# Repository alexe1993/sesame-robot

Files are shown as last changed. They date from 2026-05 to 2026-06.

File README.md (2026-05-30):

# The Sesame Robot Project 
___







sesame-cover

<p align="center">
  <a href="https://www.youtube.com/watch?v=NIgoQVQF_Ng">
    tutorial-button
  </a>
  <a href="https://discord.gg/XDXkhQd8bC">
    discord-button
  </a>
</p>

___

**Greetings, from your new best friend.**

Sesame is an accessible Open-Source robotics project based on the ESP32 microcontroller system, with an emphasis on expression and movement. 
This project is designed for makers and engineers of all skill levels! Sesame offers a dynamic platform designed to start working with walking robots. 
To build a sesame robot, you will need basic soldering skills, $50-60 in hardware components, access to a 3D printer, and a basic understanding of Arduino IDE.

This repository contains the CAD design files, STL files, build and wiring guides, and the base/expanded firmware for the ESP32-based controller. 
There is also some included debugging firmware that may be helpful in getting your Sesame up and running.

## Features

*   **Quadruped Design:** Uses 8 servo motors (2 per leg) to achieve roughly 8 total degrees of freedom.
*   **Emotive Display:** Features a 128x64 OLED screen acting as a reactive face that syncs with movement.
*   **Fully Printable:** Designed entirely for 3D printing in PLA with minimal supports.
*   **Network Connectivity:** Connect to your WiFi network for remote control and API access.
*   **JSON API:** RESTful API for programmatic control from Python, JavaScript, and more.
*   **Conversational Faces:** Expressive emotion library with talk variants for voice assistant projects.
*   **Sesame Studio:** New animation composer software to easily create custom movements.
*   **Sesame Companion App:** Python application for voice control and advanced interactions.
*   **Serial CLI:** Control the robot and trigger animations via a Serial Command Line Interface or the web UI.
*   **Pre-programmed Emotes:** Includes animations for Walking, Waving, Dancing, Pointing, Resting, and more.

## Watch the launch video on YouTube

<a href="https://www.youtube.com/watch?v=1UDsWkcQZhc">thumb-youtube</a>

___

## Getting Started

Follow these steps to build your own Sesame Robot:

### 1. Gather Parts 
Check the **[Bill of Materials (BOM)](hardware/bom/README.md)** for a complete list of required electronics and hardware.
*   Microcontroller: Lolin S2 Mini (recommended for DIY builds), Sesame Distro Board V3 (Current, pre-flashed, supports Bambu Lab battery), V2 (legacy, USB-only), or ESP32-DevKitC-32E with Distro Board V1 (legacy)
*   Actuators: 8x MG90 Servos
*   Power: 5V 3A source (USB-C PD for S2 Mini and V2 Distro Board, or battery + buck converter; see BOM for the Bambu Lab 14500 7.4V 800mAh Li-ion Battery option)

### 2. Print Parts 
Download the STLs and follow the **[Printing Guide](hardware/printing/README.md)**.
*   Designed for PLA
*   Minimal supports required

### 3. Build & Wire 
Follow the **[Build Guide](docs/build-guide/README.md)** and **[Wiring Guide](docs/wiring-guide/README.md)** to assemble the frame and connect the electronics.

### 4. Flash Firmware 
Upload the code from the **[Firmware Directory](firmware/README.md)**.
*   Requires Arduino IDE
*   Configure WiFi AP settings

### 5. Create Animations 
Use **[Sesame Studio](software/sesame-studio/README.md)** to visually design poses and sequences for your robot.

sesame-wakeup-gif

---

## Software & Firmware

### Sesame Studio
Sesame Studio is a standalone desktop application included in `software/sesame-studio/`. It allows you to:
*   Visually pose the robot using a schematic interface.
*   Generate C++ code for servo angles automatically.
*   Sequence frames into complex animations.

[**> Go to Sesame Studio**](software/sesame-studio/README.md)

### Sesame Simulator
The Sesame Simulator, created by Jay Li, is a Rust-based 3D simulation environment for testing Sesame's movements and kinematics in a virtual space. It features:
*   **Physics-based Simulation:** Test walking and balance without hardware.
*   **Web-based Interface:** Run the simulator directly in your browser.
*   **URDF Integration:** Accurate modeling of Sesame's physical properties.

[**> Go to Sesame Simulator**](https://one-for-all.github.io/sesame-robot-sim/)

### Sesame Companion App
The Sesame Companion App is a Python-based application that enables advanced control and interaction with your robot over your local network. It leverages the new JSON API and network mode features to provide:
*   **Voice Assistant Integration:** Control Sesame with voice commands and see real-time emotional expressions.
*   **Remote Control:** Command your robot from anywhere on your local network.
*   **Face Control:** Change expressions dynamically based on conversation or context.
*   **API Examples:** Reference implementation for building your own integrations.

The Companion App works with robots running the latest firmware with network mode enabled.

[**> Go to Sesame Companion App Repository**](https://github.com/dorianborian/sesame-companion-app)

### Firmware
The ESP32 firmware (`sesame-firmware-main.ino`) handles the kinematics, face display, and WiFi control interface.
*   **Web UI:** Control the robot from your phone via the built-in Access Point.
*   **Custom Faces:** Add your own bitmaps (guide in firmware docs).

[**> Go to Firmware Docs**](firmware/README.md)

---

## Contributing

This robot is a platform for building new features, cosmetics, tools, and ideas. Since the current firmware is a basic implementation, pull requests are very welcome for:
*   Kinematics improvements
*   New animations
*   Improved Web UI/UX
*   Sensor integration (Ultrasonic, Gyro, etc.)

I would also love to see forks of this project with new hardware, software, faces, etc. Be sure to send me a message if you end up building one, and I might feature you on my website or channel!
  
---

*Created by [Dorian Todd](https://www.doriantodd.com/). Need help with your Sesame Robot? Send me a message on Discord, my username is "starphee"*

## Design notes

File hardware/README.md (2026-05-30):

# Hardware

All mechanical and electrical source files for the Sesame Robot live here. The hardware stack supports multiple build paths:

- **Hand-wired / Lolin S2 Mini build** for simple protoboard construction (recommended for DIY builds).
- **Custom Sesame Distro Board V3 build** (Current) for a professional SMD design with USB-C PD 12V and specific connector for Bambu Lab battery (included in new Sesame Build Kits, pre-flashed).
- **Custom Sesame Distro Board V3/V2 build** (Legacy) professional SMD design but plagued with brownouts on battery. Recommended for USB only or bypassing the buck converter.
- **Custom Sesame Distro Board V1 build** (legacy) for ESP32-DevKitC-32E stackup (phased out but still supported).

Use the sections below to jump to the files that match the version you are assembling.

## Directory Guide

| Folder | What you will find |
| --- | --- |
| [bom](bom/README.md) | Full bill of materials covering both wiring approaches, plus power budget notes and links back to the build tutorial. Start here to gather every component before printing or soldering. |
| [cad](cad/README.md) | Parametric STEP and Fusion 360 source models for every printed part. Great for remixing joint geometry or adapting the shell—just note the caution about features that may not translate across CAD packages. |
| [pcb](pcb/README.md) | Sesame Distro Board V3 (current), V2 (legacy), and V1 (legacy) schematics, layout files, Gerber files, BOM, and Pick-and-Place files. Includes ordering instructions for PCBway fabrication and assembly services. |
| [printing](printing/README.md) | Practical PLA print settings, support callouts, and image references for joint orientation and the top cover’s manual supports. |

## Getting Started

1. **Decide on a wiring strategy.** Review the comparison section in [docs/wiring-guide/README.md](../docs/wiring-guide/README.md) to choose between the protoboard and custom PCB routes. The Lolin S2 Mini build is recommended for DIY builders. If you have a Sesame Build Kit, your V3 (or early V2) Distro Board is already pre-flashed and ready to use.
2. **Print the shell and joints.** Follow the presets in [printing/README.md](printing/README.md) to prep the 3D files from `hardware/printing/stl`.
3. **Source electronics.** Use the line-by-line list in [bom/README.md](bom/README.md) and verify your power supply meets the 5V/3A requirement.
4. **Assemble electronics.** Reference either the hand-wiring steps or the appropriate Distro Board guide plus the wiring diagrams in `docs/wiring-guide/`.

> [!TIP]
> Keep photos of your wiring progress. They are invaluable for troubleshooting later and help when sharing build notes with the community.

## Supporting Documents

- [docs/build-guide/README.md](../docs/build-guide/README.md) for end-to-end assembly sequencing.
- [docs/wiring-guide/README.md](../docs/wiring-guide/README.md) for wiring diagrams, safety notes, and packing tips.

Improvements, remixes, and test reports are welcome, file issues or PRs with any updates you discover while building. <3

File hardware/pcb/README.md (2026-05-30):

# PCB Schematics

Electronic schematics and PCB designs for the Sesame Robot Project. There are two versions of the Sesame Distro Board available: V3 (current), V2 (legacy), and V1 (legacy).

> [!NOTE]
> **For Sesame Build Kits:** All Sesame Build Kits include a pre-flashed Sesame Distro Board V3 (or earlier V2), so you don't need to order or assemble a board separately.

> [!TIP]
> **Building from Scratch?** If you're building a Sesame Robot from scratch, we recommend using the **S2 Mini with hand wiring approach** for the easiest assembly experience. The V2/V3 distro boards use advanced SMD components that require specialized soldering skills or PCB assembly services.

---

## Sesame Distro Board V3 (Current)

The **Sesame Distro Board V3** is the latest version and features:

- **ESP32-S3 Processor**
- **USB-C PD 12V** (requires high quality PD charger cable)
- **Bambu Lab 14500 Battery Connector** for cheap and effective battery powering (priority feature)
- One-click order link via PCBway: [Order On PCBway!](https://www.pcbway.com/project/shareproject/Sesame_Distro_Board_V3_377de6fe.html)
- Limited stock of pre-assembled units: [Full Contact Engineering](https://fullcontactengineering.com/products/sesame-distro-board-v3-pcb)
  *Note: Due to time constraints, the USB-C PD 12V negotiation chip is slightly untested, so a high quality PD cable is necessary.*

### V3 Board Details and Schematics:

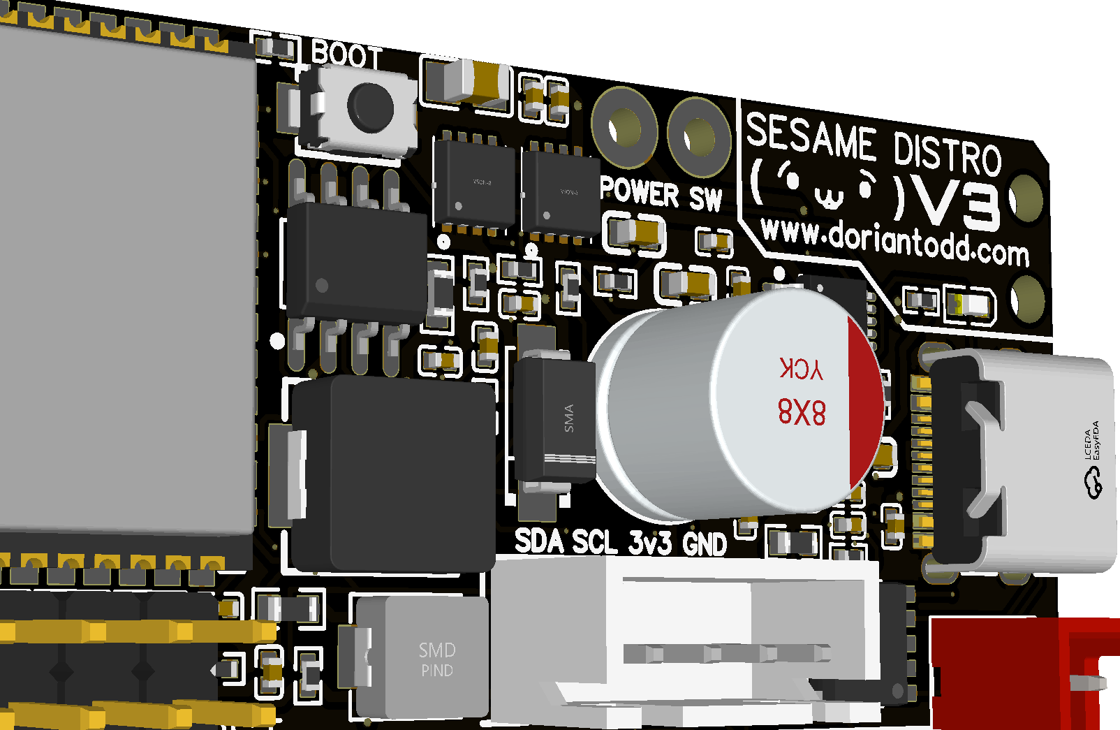
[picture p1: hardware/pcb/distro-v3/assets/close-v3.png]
Sesame Distro Board V3 Close-up


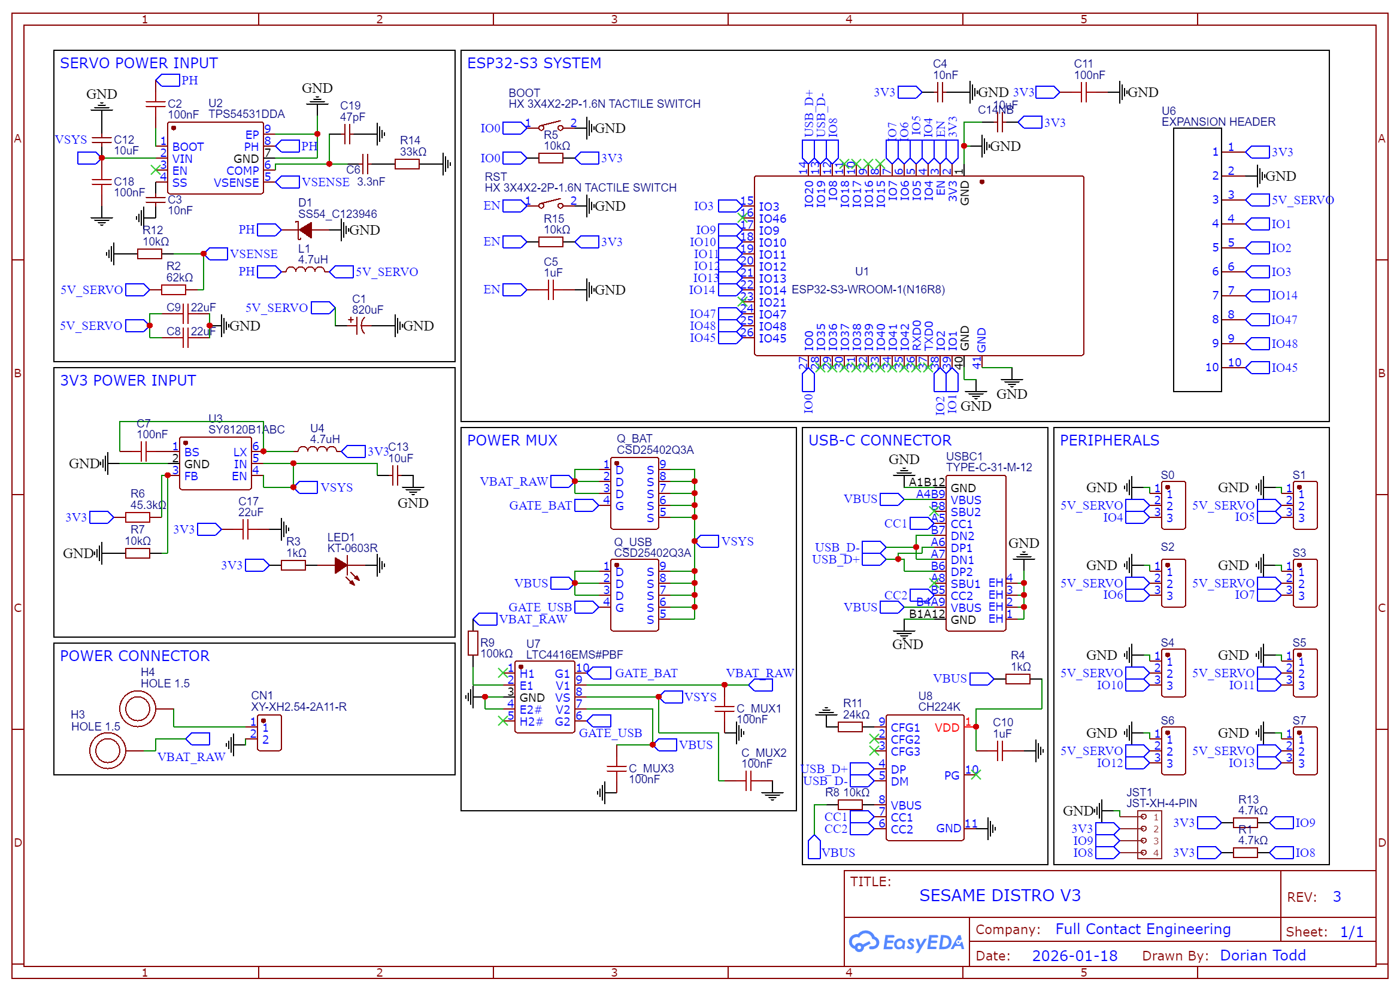
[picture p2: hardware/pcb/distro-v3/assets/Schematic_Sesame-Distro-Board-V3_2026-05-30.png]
Schematic_Sesame-Distro-Board-V3


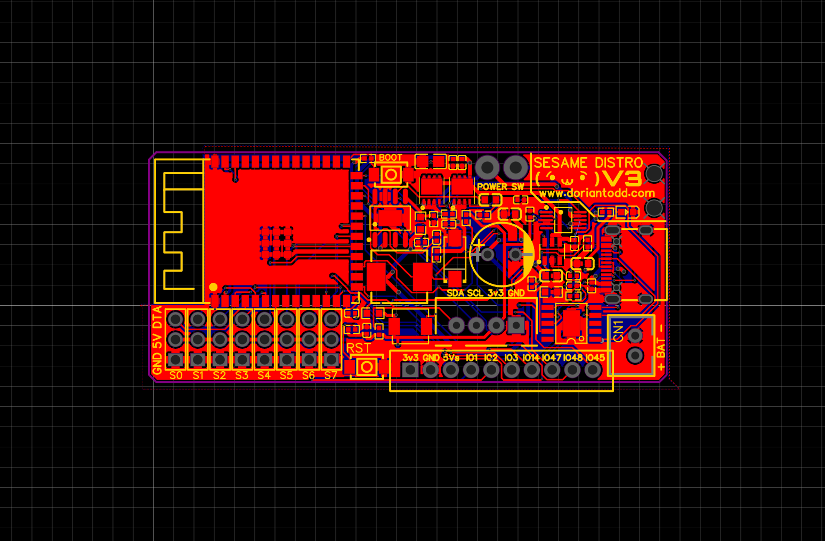
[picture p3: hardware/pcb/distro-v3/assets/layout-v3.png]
Sesame Distro Board V3 Layout


### V3 Files Available

All files are located in the [`distro-v3/`](distro-v3/) directory:

- **Schematic source:** `SCH_Sesame-Distro-Board-V3.json` - EasyEDA source design file for the V3 schematic
- **Gerber file:** `Gerber_Sesame-Distro-Board-V3_PCB.zip` - For PCB fabrication
- **BOM file:** `BOM_Sesame-Distro-Board-V3.csv` - Bill of materials for SMD components
- **Pick-and-Place file:** `PickAndPlace_PCB_Sesame-Distro-Board-V3.csv` - Component placement data for assembly

## Sesame Distro Board V2 (Legacy)

The **Sesame Distro Board V2** is an older version. *Major instabilities on battery power (brownouts due to buck converter handling) restrict this to USB only, or you must bypass the chip by soldering a separate buck converter directly to the power line. I may have extra V3 boards to send to those who ordered V2.*

### V2 Assembly Options (Legacy)

The V2 board consists entirely of SMD (surface-mount) components, which are **advanced to hand solder**. We recommend:

1. **PCB Assembly Service (Recommended):** Use [PCBway&#39;s PCB assembly service](https://www.pcbway.com/pcb-assembly.html) to have the board professionally assembled. Upload the Gerber, BOM, and Pick-and-Place files to their assembly service.
2. **Hand Soldering (Advanced Only):** Only attempt hand soldering if you're experienced with SMD components and have the proper tools (hot air station, fine-tip soldering iron, flux, etc.).

### V2 Files Available

All files are located in the [`distro-v2/`](distro-v2/) directory:

- **Schematic source:** `SCH_Sesame-Distro-Board-V2_2026-03-06.json` - EasyEDA source design file for the V2 schematic
- **Gerber file:** `Gerber_Sesame-Distro-V2_PCB.zip` - For PCB fabrication
- **BOM file:** `BOM_Sesame-Distro-V2.csv` - Bill of materials for SMD components
- **Pick-and-Place file:** `PickAndPlace_PCB_Sesame-Distro-V2.csv` - Component placement data for assembly

### PCBway / JLCPCB Sourcing Notes

When uploading the BOM to PCBway or JLCPCB for assembly, note the following three components that require special handling:

| Designator | Issue | Corrected Part | LCSC # |
| --- | --- | --- | --- |
| `U5`, `U7` | **Solder Pads** — these are copper pads only, no physical component is needed. Remove these lines from the BOM when ordering assembly. | N/A | N/A |
| `5-12V` | 2-pin 3.5 mm screw terminal. Original part `1984617` (Phoenix Contact) cannot be sourced. | `XY302V-3.5-2P` | [C784940](https://www.lcsc.com/product-detail/C784940.html) |
| `JST-XH` | 4-pin JST XH connector. Original `JST-XH-4-PIN` cannot be sourced. | `B4B-XH-A(LF)(SN)` | [C144395](https://www.lcsc.com/product-detail/C144395.html) |

The BOM CSV has already been updated with the corrected parts. The solder-pad rows are marked **"No Part Required"** in the Name field so they are easy to identify and exclude.

---

## Sesame Distro Board V1 (Legacy)

> [!CAUTION]
> The Sesame Distro Board V1 is now **phased out** but still supported. V1 has some limitations: it won't run on tethered power (e.g., USB-C) and is harder to assemble than other options. V1 is still supported with wiring guides and firmware and works on battery power. If you have a V1 board, you can still use it successfully.

The Distro Board V1 pairs with the ESP32-DevKitC-32E.

> [!IMPORTANT]
> **ESP32 Pin Header Requirement:** The distro board V1 stacks on top of the ESP32-DevKitC-32E, so you need an ESP32 board **without pre-soldered pin headers**. If your board came with headers already soldered on the top, you will need to desolder all of the headers and flip them to the bottom side of the ESP32 board so the distro board can mount on top.

### V1 Board Schematic:

Schematic_Sesame-Distro-Board

### V1 Files Available

All files are located in the [`distro-v1/`](distro-v1/) directory.

---

## PCBway Sponsorship

**PCBway Sponsorship**

This project was sponsored by [PCBway](https://www.pcbway.com/), who manufactured the custom distro boards. PCBway offers high-quality PCB fabrication services with fast turnaround times and excellent customer support.

If you're building your own Sesame Robot, PCBway is a great option for getting professional-quality PCB fabrication and assembly services at reasonable prices:

- **PCB Fabrication:** Upload Gerber files to get boards manufactured
- **PCB Assembly:** Upload Gerber, BOM, and Pick-and-Place files for fully assembled boards (recommended for V2)

pcbs-from-pcbway

---

## How to Order

### Ordering V3 Boards (Current)

**Option 1: Pre-assembled Units (Recommended)**
Depending on stock availability, you can buy fully populated, pre-flashed boards directly from [Full Contact Engineering](https://fullcontactengineering.com/products/sesame-distro-board-v3-pcb).

**Option 2: PCBway Assembly Service**

1. Go to [PCBway&#39;s Shared Project Page](https://www.pcbway.com/project/shareproject/Sesame_Distro_Board_V3_377de6fe.html)
2. Add to cart to order the boards fully assembled!

**Option 3: Manual PCBway Assembly Service Upload**

1. Go to [PCBway&#39;s PCB Assembly service](https://www.pcbway.com/pcb-assembly.html)
2. Upload the Gerber file: `distro-v3/Gerber_Sesame-Distro-Board-V3_PCB.zip`
3. Upload the BOM file: `distro-v3/BOM_Sesame-Distro-Board-V3.csv`
4. Upload the Pick-and-Place file: `distro-v3/PickAndPlace_PCB_Sesame-Distro-Board-V3.csv`
5. Confirm board specifications and component availability

### Ordering V2 Boards (Deprecated)

**Option 1: PCB Assembly Service (Recommended)**

1. Go to [PCBway&#39;s PCB Assembly service](https://www.pcbway.com/pcb-assembly.html)
2. Upload the Gerber file: `distro-v2/Gerber_Sesame-Distro-V2_PCB.zip`
3. Upload the BOM file: `distro-v2/BOM_Sesame-Distro-V2.csv`
4. Upload the Pick-and-Place file: `distro-v2/PickAndPlace_PCB_Sesame-Distro-V2.csv`
5. Confirm board specifications and component availability
6. Place your order to receive fully assembled boards

**Option 2: Fabrication Only (For Advanced Users)**

1. Download the Gerber file from [`distro-v2/Gerber_Sesame-Distro-V2_PCB.zip`](distro-v2/Gerber_Sesame-Distro-V2_PCB.zip)
2. Upload to [PCBway](https://www.pcbway.com/) or another PCB manufacturer
3. Confirm board specifications in the preview
4. Order the bare PCBs and hand-solder SMD components yourself (advanced)

### Ordering V1 Boards (Legacy)

1. Download the Gerber file from [`distro-v1/Gerber_Sesame-Distro-Board_PCB_Sesame-Distro-Board_V1.zip`](distro-v1/Gerber_Sesame-Distro-Board_PCB_Sesame-Distro-Board_V1.zip)
2. Upload to [PCBway](https://www.pcbway.com/) or another PCB manufacturer
3. Confirm board specifications in the preview
4. Place your order to receive bare V1 boards

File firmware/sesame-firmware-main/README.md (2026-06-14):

# esame Robot Firmware

This document provides technical information on the firmware architecture, control logic, and hardware abstraction layers used in the Sesame Robot.

> [!NOTE]
> The firmware is now organized into a modular structure with a main entry point and specialized header files for bitmaps, movement, and web assets. This makes customization much easier and the codebase cleaner.

## Table of Contents

- [How to Flash the Firmware](#how-to-flash-the-firmware)
- [Network Configuration](#network-configuration--connectivity)
- [API Reference](#api-reference)
  - [Legacy Web Endpoints](#legacy-web-endpoints)
  - [JSON API](#json-api-recommended-for-network-clients)
  - [Python Examples](#python-api-example)
  - [JavaScript Examples](#nodejsjavascript-example)
- [Advanced Integration Examples](#advanced-integration-examples)
  - [Voice Assistant Integration](#voice-assistant-integration)
  - [Home Automation](#home-automation-integration)
- [Idle Animation System](#idle-animation-system)
- [Firmware Architecture](#firmware-architecture)
- [Technical Implementation](#technical-implementation-overview)
- [Asset Pipeline &amp; Face Customization](#asset-pipeline--face-customization)
- [Hardware Abstraction Layer](#hardware-abstraction-layer-hal)

## How to Flash the Firmware

> [!NOTE]
> **Sesame Build Kit Users:** Your Distro Board V3 (and earlier V2) kits come pre-flashed with the latest firmware. You only need to flash firmware if you want to customize it or update to a newer version.

### Prerequisites

1. **Arduino IDE** (version 2.0 or higher recommended)
2. **ESP32 Board Support**: Install via Arduino IDE's Board Manager
   - Open Arduino IDE
   - Go to **File → Preferences**
   - Add to "Additional Board Manager URLs": `https://raw.githubusercontent.com/espressif/arduino-esp32/gh-pages/package_esp32_index.json`
   - Go to **Tools → Board → Boards Manager**
   - Search for "ESP32" and install "ESP32 by Espressif Systems" (v2.0.0 or higher)
3. **Required Libraries** (install via Library Manager):

- `Adafruit PWM Servo Driver Library`
- `Adafruit SSD1306`
- `Adafruit GFX Library`

> [!IMPORTANT]
> The firmware expects a PCA9685 servo driver at I2C address `0x40`. The SSD1306 display shares the same SDA/SCL bus and is detected at `0x3C` or `0x3D`.

### Flashing Steps

1. **Connect your board** via USB to your computer
2. **Open the firmware**:

   - Open [sesame-firmware-main.ino](sesame-firmware-main.ino) in Arduino IDE
   - Make sure you have it in a folder with the same name.
   - Also include all of the .h header files.
3. **Select your board**:

   - Go to **Tools → Board**
   - For Lolin S2 Mini: Select "LOLIN S2 Mini"
   - For Sesame Distro Board V1: Select "ESP32 Dev Module"
   - For Sesame Distro Board V2 or V3: Select "ESP32S3 Dev Module"
4. **Configure board settings**:

   - **For Lolin S2 Mini**:
     - **Upload Speed**: 921600
     - **USB CDC On Boot**: "Enabled"
     - **Partition Scheme**: "Default 4MB with spiffs"
   - **For Distro Board V2 or V3 (ESP32-S3)**:
     - **USB CDC On Boot**: "Enabled" (Required for Serial Monitor)
     - **Flash Mode**: "QIO 80MHz"
     - **Partition Scheme**: "Default 4MB with spiffs"
5. **Select the correct port**:

   - Go to **Tools → Port** and select your ESP32's COM port
6. **Choose your board configuration** in the code:

   - Open [sesame-firmware-main.ino](sesame-firmware-main.ino)
   - The firmware uses `Wire.begin()` and the selected board's default I2C pins.
   - Connect servos 0-7 to PCA9685 channels 0-7. No individual ESP32 servo GPIO configuration is required.
7. **(Optional) Configure network mode**:

   - If you want the robot to connect to your WiFi network (for API access and remote control), edit the network configuration section (around line 17-22):

   ```cpp
   #define NETWORK_SSID "YourNetworkName"  // Your WiFi network name
   #define NETWORK_PASS "YourPassword"     // Your WiFi password
   #define ENABLE_NETWORK_MODE true        // Set to true to enable
   ```

   - Leave `ENABLE_NETWORK_MODE false` to use Access Point mode only
8. **Upload the firmware**:

   - Click the **Upload** button (→) in Arduino IDE
   - Wait for compilation and upload to complete
9. **Test the connection**:

   - Open Serial Monitor (**Tools → Serial Monitor**, set baud rate to 115200)
   - Reset the board - you should see startup messages and network information
   - The serial monitor provides individual motor control for testing and troubleshooting
   - **If using AP mode only**: Connect to the "Sesame-Controller-BETA" WiFi network (password: `12345678`) and navigate to any website
   - **If using network mode**: Look for the "Connected to network!" message in Serial Monitor, then access via `http://sesame-robot.local` or the displayed IP address

### Troubleshooting

- **Linux USB Permissions**: If your port isn't showing up or you get "Permission Denied", you likely need to add your user to the `dialout` group: `sudo usermod -a -G dialout $USER`. Log out and back in for changes to take effect.
- **Upload fails**: Try holding the BOOT button while uploading, or try a different USB cable. For S3-based boards, the "USB CDC On Boot" setting is critical for finding the port after a reset.
- **Port not found**: Install the appropriate USB drivers (CP210x for S2 Mini, CH340 for some ESP32 boards). Windows 10/11 usually includes these.
- **Robot not moving**: Check power supply and servo connections; increase `motorCurrentDelay` in web settings if brownouts occur
- **Can't connect to network**:
  - Verify `ENABLE_NETWORK_MODE` is set to `true` and SSID/password are correct
  - Check Serial Monitor for connection status - look for "Connected to network!" or error messages
  - Ensure your WiFi network is 2.4GHz (ESP32 does not support 5GHz)
  - Try increasing the connection timeout in the code (currently 10 seconds / 20 attempts)
- **mDNS hostname not resolving**:
  - On Windows, install [Bonjour Print Services](https://support.apple.com/kb/DL999)
  - On Linux, ensure `avahi-daemon` is installed and running
  - Try accessing via IP address instead (check Serial Monitor for the assigned IP)
  - Some routers block mDNS traffic - check router settings or use IP address
- **API commands not working**:
  - Ensure you're sending POST requests to `/api/command` (not GET)
  - Verify `Content-Type: application/json` header is set
  - Check Serial Monitor for error messages and parsed command output
  - Test with a simple cURL command first to verify connectivity

## Firmware Architecture

The firmware is split into several key files to keep the logic organized and assets easy to manage:

- **[sesame-firmware-main.ino](sesame-firmware-main.ino)**: The main entry point containing the `setup()`, `loop()`, core system logic, network configuration, and API endpoints.
- **[face-bitmaps.h](face-bitmaps.h)**: A dedicated header for OLED face macros and raw bitmap data. Now includes extensive conversational faces for voice assistant integration.
- **[movement-sequences.h](movement-sequences.h)**: Definitions for all procedural movement and pose animations.
- **[captive-portal.h](captive-portal.h)**: Contains the HTML, CSS, and JS for the web-based remote control interface.

## Technical Implementation Overview

The firmware is built on the Arduino-ESP32 framework. It runs on a single-core event loop and delegates servo PWM generation to a PCA9685 driver.

### PWM & Servo Kinematics

- **External PWM**: A PCA9685 at I2C address `0x40` generates all eight 50 Hz servo signals, avoiding ESP32 PWM timer allocation and direct servo GPIO wiring.
- **Pulse Width Mapping**: Leg servos are mapped from degrees (0-180) to microseconds (500us to 2500us), matching the tested PCA9685 Spider sketch. Edit `SERVO_MIN_US` and `SERVO_MAX_US` near the top of `sesame-firmware-main.ino` for a different servo range.
- **Staggered Activation**: To prevent VCC rail collapse (brownout) caused by simultaneous inductive loads, the `setServoAngle` helper introduces a mandatory `motorCurrentDelay` (default 20ms) between sequential pulses. This delay should be tweaked to your power setup. If you have a strong dedicated power supply you can try setting it to zero. It can also be changed while running through the AP controller settings menu.

### Communication & Networking Stack

- **Dual-Mode WiFi**: The ESP32 can simultaneously operate in both Access Point mode (for direct connections) and Station mode (connected to an existing network) using `WiFi.mode(WIFI_AP_STA)`.
- **SoftAP & Captive Portal**: The ESP32 initializes an Access Point using `WiFi.softAP()`. A `DNSServer` listens on UDP Port 53, using a wildcard "*" redirect to map all DNS queries to the internal gateway (`192.168.4.1`).
- **mDNS Service Discovery**: The firmware broadcasts `sesame-robot.local` via Multicast DNS (mDNS) using the `ESPmDNS` library, allowing network discovery without hardcoded IP addresses.
- **RESTful API Surface**: The `WebServer` handles both legacy URL-parameter endpoints and modern JSON-based API:
  - `/cmd?go=[dir]`: Legacy movement control
  - `/cmd?pose=[name]`: Legacy pose triggers
  - `/api/status`: JSON status endpoint (GET)
  - `/api/command`: JSON command endpoint (POST) - supports face-only updates and combined face+movement commands
  - `/getSettings` / `/setSettings`: Parameter configuration
- **Face-Only Command Support**: The `/api/command` endpoint intelligently detects face-only requests (no `command` field) and updates the display without triggering movement animations.
- **Non-Blocking Control Flow**: Instead of `delay()`, the firmware uses a custom `pressingCheck(String cmd, int ms)` function. This function polls `server.handleClient()` and `dnsServer.processNextRequest()` during animation frames, allowing for real-time interruptibility (e.g., immediate stop on button release). This pressingCheck protocol can be used for motion commands like walking to play each motion only when the button is held.

### Display & Graphics Subsystem

- **Shared I2C Bus**: The PCA9685 (`0x40`) and SSD1306 (`0x3C` or `0x3D`) share the ESP32 hardware I2C bus.
- **Memory Management (`PROGMEM`)**: Large 128x64 bitmap arrays (1024 bytes per frame) are stored in Flash memory using the `PROGMEM` attribute.
- **Macro-Based Asset Management**: The firmware uses a `FACE_LIST` macro in [face-bitmaps.h](face-bitmaps.h) to automatically register and handle new faces, reducing the boilerplate required when adding animations.
- **Rendering Pipeline**: The `updateAnimatedFace()` function manages frame rates and sequence looping outside of the main movement logic to ensure smooth visual feedback even during complex movements.
- **Dynamic WiFi Info Overlay**: The `updateWifiInfoScroll()` function composites scrolling connection information over the face bitmap during the first 30 seconds of operation (before first input), drawing the face as background with a black bar and white text overlay for readability.
- **Idle Animation System**: Implements realistic idle behavior with randomized blinking (including double-blinks) and boomerang face animations, triggered automatically when no input is detected.

## Prerequisites & Development Environment

- **Board Support**: ESP32 by Espressif Systems (v2.0.0+ recommended). Lolin S2 Mini and ESP32-WROOM32 DevKitC are best supported.
- **Libraries**:
  - `Adafruit_PWMServoDriver`: PCA9685 servo PWM control.
  - `Adafruit_SSD1306` & `Adafruit_GFX`: Buffer-based OLED rendering.
  - `ESPmDNS`: mDNS service discovery (included with ESP32 board support).
  - `DNSServer`: Captive portal DNS redirection (included with ESP32 board support).
  - `WebServer`: HTTP server implementation (included with ESP32 board support).
- **Tooling**: Arduino IDE 2.0+ recommended.

## Network Configuration & Connectivity

The firmware now supports **dual-mode WiFi operation**, allowing the robot to simultaneously act as an Access Point (for direct connections) and connect to your existing WiFi network (for integration with other devices and remote control).

### Access Point Mode (Default)

By default, the robot creates its own WiFi network:

- **SSID**: `Sesame-Controller-BETA`
- **Password**: `12345678` (Some devices may require you to change this if the default isn't connecting)
- **IP Address**: `192.168.4.1`

Connect to this network and navigate to any website to access the captive portal control interface. If you're having trouble connecting, try changing the password to something custom in the code's `#define AP_PASS` section.

### Network Mode (Optional)

To connect the robot to your home or office WiFi network:

1. **Enable Network Mode** in [sesame-firmware-main.ino](sesame-firmware-main.ino):

   ```cpp
   #define NETWORK_SSID "YourNetworkName"  // Your WiFi network name
   #define NETWORK_PASS "YourPassword"     // Your WiFi password
   #define ENABLE_NETWORK_MODE true        // Set to true to enable
   ```
2. **Flash the updated firmware** to your robot.
3. **Access via multiple methods**:

   - **mDNS Hostname**: `http://sesame-robot.local` (works on most devices)
   - **Network IP**: Check Serial Monitor at 115200 baud for the assigned IP address
   - **Still accessible via AP**: The robot maintains its Access Point even when connected to your network

### mDNS Discovery

The firmware includes an mDNS responder that broadcasts the hostname `sesame-robot.local` on your local network. This allows you to access the robot without knowing its IP address:

```bash
# Access from browser
http://sesame-robot.local

# Ping test
ping sesame-robot.local
```

**Note**: mDNS works natively on:

- macOS and iOS devices
- Linux with Avahi installed
- Windows 10+ (may require Bonjour service)

### Security Considerations

The firmware is designed for local network use and does not include authentication by default. When enabling network mode:

- **Local Network Only**: The robot responds to requests from any device on your network. Do not expose it to the internet without proper security measures.
- **No HTTPS**: Communication is unencrypted HTTP. Avoid transmitting sensitive data through the robot's API.
- **Access Point Password**: The default AP password is `12345678`. For production use, change `AP_PASS` in the firmware to a stronger password.
- **Trusted Networks**: Only connect your robot to trusted WiFi networks.

For enhanced security:

1. Change the default AP password to a strong, unique password
2. Use network segmentation (IoT VLAN) to isolate the robot from critical devices
3. Implement firewall rules to restrict access to specific IP addresses
4. Consider adding authentication headers in a custom firmware fork for production deployments

### WiFi Information Display

The robot's OLED screen now features an intelligent WiFi info system:

- **First 30 seconds**: If no input is received, WiFi connection information scrolls across the top of the display
- **After first input**: WiFi info disappears to show only faces
- **Dual-mode info**: When connected to both AP and network, displays both connection details

The scrolling text includes:

- Access Point SSID and IP
- Network name and IP (if connected)
- mDNS hostname
- Captive portal instructions

## API Reference

The firmware exposes both legacy web endpoints and a modern JSON-based API for programmatic control.

### Legacy Web Endpoints

These endpoints use URL parameters and are primarily used by the web interface:

#### Movement Control

```http
GET /cmd?go=forward
GET /cmd?go=backward
GET /cmd?go=left
GET /cmd?go=right
GET /cmd?stop
```

#### Pose Control

```http
GET /cmd?pose=wave
GET /cmd?pose=dance
GET /cmd?pose=rest
GET /cmd?pose=stand
# ... (see movement-sequences.h for all available poses)
```

#### Individual Motor Control

```http
GET /cmd?motor=1&value=90
# motor: 1-8 (motor number)
# value: 0-180 (angle in degrees)
```

#### Settings Management

```http
GET /getSettings
# Returns: {"frameDelay":100,"walkCycles":10,"motorCurrentDelay":20,"faceFps":8}

GET /setSettings?frameDelay=120&walkCycles=15&motorCurrentDelay=25&faceFps=10
```

### JSON API (Recommended for Network Clients)

The JSON API is designed for programmatic control from external devices, Python scripts, and IoT integrations.

#### Get Robot Status

```http
GET /api/status
```

**Response:**

```json
{
  "currentCommand": "forward",
  "currentFace": "walk",
  "networkConnected": true,
  "apIP": "192.168.4.1",
  "networkIP": "192.168.1.100"
}
```

#### Send Commands

```http
POST /api/command
Content-Type: application/json

{
  "command": "forward",
  "face": "walk"
}
```

**Response:**

```json
{
  "status": "ok",
  "message": "Command executed"
}
```

#### Face-Only Updates

Send a face change without triggering movement:

```http
POST /api/command
Content-Type: application/json

{
  "face": "happy"
}
```

**Response:**

```json
{
  "status": "ok",
  "message": "Face updated"
}
```

#### Stop Command

```http
POST /api/command
Content-Type: application/json

{
  "command": "stop"
}
```

### Available Commands

**Movement Commands:**

- `forward`, `backward`, `left`, `right` - Continuous movement (loops until stopped)
- `stop` - Immediately stop current movement

**Pose Commands (one-shot animations):**

- `rest`, `stand`, `wave`, `dance`, `swim`, `point`
- `pushup`, `bow`, `cute`, `freaky`, `worm`, `shake`
- `shrug`, `dead`, `crab`

**Available Faces:**

- Movement faces: `walk`, `rest`, `stand`, `dance`, `wave`, etc.
- Conversational faces: `happy`, `sad`, `angry`, `surprised`, `sleepy`, `love`, `excited`, `confused`, `thinking`
- Talk variants: `talk_happy`, `talk_sad`, `talk_angry`, etc.
- Special: `idle`, `idle_blink`, `default`

### Python API Example

```python
import requests
import time

# Robot IP or hostname
robot_url = "http://sesame-robot.local"

# Get status
response = requests.get(f"{robot_url}/api/status")
status = response.json()
print(f"Current face: {status['currentFace']}")

# Make robot wave and show happy face
requests.post(f"{robot_url}/api/command", json={
    "command": "wave",
    "face": "happy"
})

time.sleep(3)

# Just change face without moving
requests.post(f"{robot_url}/api/command", json={
    "face": "excited"
})

# Stop movement
requests.post(f"{robot_url}/api/command", json={
    "command": "stop"
})
```

### cURL Examples

```bash
# Get robot status
curl http://sesame-robot.local/api/status

# Make robot dance
curl -X POST http://sesame-robot.local/api/command \
  -H "Content-Type: application/json" \
  -d '{"command":"dance","face":"dance"}'

# Change face only
curl -X POST http://sesame-robot.local/api/command \
  -H "Content-Type: application/json" \
  -d '{"face":"happy"}'

# Stop movement
curl -X POST http://sesame-robot.local/api/command \
  -H "Content-Type: application/json" \
  -d '{"command":"stop"}'
```

### Node.js/JavaScript Example

```javascript
const robotURL = 'http://sesame-robot.local';

// Get status
fetch(`${robotURL}/api/status`)
  .then(res => res.json())
  .then(data => console.log('Robot status:', data));

// Send command
fetch(`${robotURL}/api/command`, {
  method: 'POST',
  headers: {'Content-Type': 'application/json'},
  body: JSON.stringify({
    command: 'wave',
    face: 'happy'
  })
})
.then(res => res.json())
.then(data => console.log('Response:', data));

// Face-only update
fetch(`${robotURL}/api/command`, {
  method: 'POST',
  headers: {'Content-Type': 'application/json'},
  body: JSON.stringify({face: 'surprised'})
})
.then(res => res.json())
.then(data => console.log('Response:', data));
```

## Advanced Integration Examples

### Voice Assistant Integration

The combination of conversational faces, the JSON API, and network mode makes the Sesame Robot perfect for voice assistant projects. Here's an example using Python with speech recognition:

```python
import requests
import speech_recognition as sr
from textblob import TextBlob
import time

robot_url = "http://sesame-robot.local"

def analyze_sentiment(text):
    """Analyze sentiment and return appropriate face"""
    blob = TextBlob(text)
    polarity = blob.sentiment.polarity
  
    if polarity > 0.5:
        return "excited"
    elif polarity > 0.2:
        return "happy"
    elif polarity < -0.5:
        return "angry"
    elif polarity < -0.2:
        return "sad"
    else:
        return "thinking"

def set_robot_face(face, talking=False):
    """Update robot's face expression"""
    if talking:
        face = f"talk_{face}"
  
    requests.post(f"{robot_url}/api/command", json={"face": face})

# Initialize speech recognition
recognizer = sr.Recognizer()

while True:
    with sr.Microphone() as source:
        print("Listening...")
        set_robot_face("idle")
    
        try:
            audio = recognizer.listen(source, timeout=5)
            set_robot_face("thinking")
        
            text = recognizer.recognize_google(audio)
            print(f"You said: {text}")
        
            # Determine emotion and show talking face
            emotion = analyze_sentiment(text)
            set_robot_face(emotion, talking=True)
        
            # Process command...
            time.sleep(2)
        
            # Return to neutral
            set_robot_face(emotion, talking=False)
        
        except sr.WaitTimeoutError:
            set_robot_face("sleepy")
        except sr.UnknownValueError:
            set_robot_face("confused")
```

### Home Automation Integration

Integrate with Home Assistant or other home automation platforms:

```python
# Home Assistant automation example
import requests

def robot_notification(message_type):
    """Display robot emotion based on notification type"""
    robot_url = "http://sesame-robot.local"
  
    emotion_map = {
        "doorbell": "surprised",
        "alarm": "angry",
        "reminder": "thinking",
        "success": "happy",
        "error": "sad"
    }
  
    face = emotion_map.get(message_type, "default")
    requests.post(f"{robot_url}/api/command", json={"face": face})
  
    # Optional: add movement
    if message_type == "doorbell":
        requests.post(f"{robot_url}/api/command", json={
            "command": "wave",
            "face": "happy"
        })
```

### WebSocket Streaming (Advanced)

For real-time control with minimal latency, you can poll the status endpoint or implement a simple state machine:

```javascript
// React/Vue.js real-time robot control
class RobotController {
  constructor(robotURL) {
    this.url = robotURL;
    this.currentFace = 'default';
  }
  
  async updateEmotion(emotion, isSpeaking) {
    const face = isSpeaking ? `talk_${emotion}` : emotion;
  
    if (face !== this.currentFace) {
      await fetch(`${this.url}/api/command`, {
        method: 'POST',
        headers: {'Content-Type': 'application/json'},
        body: JSON.stringify({face})
      });
  
      this.currentFace = face;
    }
  }
  
  async getStatus() {
    const res = await fetch(`${this.url}/api/status`);
    return await res.json();
  }
  
  async performAction(action, emotion = null) {
    const payload = {command: action};
    if (emotion) payload.face = emotion;
  
    await fetch(`${this.url}/api/command`, {
      method: 'POST',
      headers: {'Content-Type': 'application/json'},
      body: JSON.stringify(payload)
    });
  }
}

// Usage
const robot = new RobotController('http://sesame-robot.local');

// Set emotion without moving
await robot.updateEmotion('happy', false);

// Set talking face
await robot.updateEmotion('excited', true);

// Perform action with face
await robot.performAction('dance', 'excited');

// Check status
const status = await robot.getStatus();
console.log(`Robot is ${status.currentFace} and doing ${status.currentCommand}`);
```

## Idle Animation System

The firmware includes an intelligent idle animation system that activates automatically:

### Behavior

- **Activation**: When the robot has received no commands for a period, it enters idle mode
- **Idle Face**: Displays a gentle "breathing" animation using the `idle` face in `FACE_ANIM_BOOMERANG` mode
- **Blinking**: Randomly triggers blink animations (3-7 second intervals)
- **Double Blinks**: 30% chance of a double blink for realistic behavior
- **Exit**: Any movement command or input immediately exits idle mode

### Technical Implementation

The idle system uses:

- `enterIdle()` - Activates idle face with boomerang animation
- `exitIdle()` - Returns to normal operation
- `updateIdleBlink()` - Manages random blink timing and double-blink logic
- `scheduleNextIdleBlink()` - Randomizes blink intervals for natural appearance

To customize idle behavior, modify the timing values in [sesame-firmware-main.ino](sesame-firmware-main.ino):

```cpp
scheduleNextIdleBlink(3000, 7000);  // Min and max ms between blinks
```

## Asset Pipeline & Face Customization

The firmware includes an intelligent idle animation system that activates automatically:

### Behavior

- **Activation**: When the robot has received no commands for a period, it enters idle mode
- **Idle Face**: Displays a gentle "breathing" animation using the `idle` face in `FACE_ANIM_BOOMERANG` mode
- **Blinking**: Randomly triggers blink animations (3-7 second intervals)
- **Double Blinks**: 30% chance of a double blink for realistic behavior
- **Exit**: Any movement command or input immediately exits idle mode

### Technical Implementation

The idle system uses:

- `enterIdle()` - Activates idle face with boomerang animation
- `exitIdle()` - Returns to normal operation
- `updateIdleBlink()` - Manages random blink timing and double-blink logic
- `scheduleNextIdleBlink()` - Randomizes blink intervals for natural appearance

To customize idle behavior, modify the timing values in [sesame-firmware-main.ino](sesame-firmware-main.ino):

```cpp
scheduleNextIdleBlink(3000, 7000);  // Min and max ms between blinks
```

## Hardware Abstraction Layer (HAL)

The firmware uses the selected ESP32 board's default I2C pins. Servo outputs come from PCA9685 channels 0-7, while the SSD1306 display is connected to the same SDA/SCL bus.

### PCA9685 Channel Map

| Servo | PCA9685 Channel | Leg |
| ----- | --- | --- |
| Motor 0 | 0 | R1 |
| Motor 1 | 1 | R2 |
| Motor 2 | 2 | L1 |
| Motor 3 | 3 | L2 |
| Motor 4 | 4 | R4 |
| Motor 5 | 5 | R3 |
| Motor 6 | 6 | L3 |
| Motor 7 | 7 | L4 |

### ESP32 I2C Pins

| Board | SDA | SCL |
| ----- | --- | --- |
| Lolin S2 Mini | 33 | 35 |
| Sesame Distro Board V1 | 21 | 22 |
| Sesame Distro Board V2 / V3 | 8 | 9 |

Connect both the PCA9685 and SSD1306 to these SDA/SCL pins. Grounds must be common between the ESP32, PCA9685 logic, display, and servo power supply. Power the servos through the PCA9685 `V+` rail from a suitable external supply, not from the ESP32 3.3 V pin.

### Porting to Other ESP32 Variants

The firmware calls `Wire.begin()` to use the default SDA/SCL pins supplied by the selected Arduino board definition. For custom wiring, replace it with `Wire.begin(SDA_PIN, SCL_PIN)`; both pins must support output because I2C data and clock are bidirectional.

## Asset Pipeline & Face Customization

To maintain a clean main source file and optimize performance, face bitmaps are decoupled from the primary logic. Faces are managed in [face-bitmaps.h](face-bitmaps.h) using a "Single Source of Truth" macro system.

### Face Library

The firmware includes an extensive library of faces organized into three categories:

#### Movement Faces

Synchronized with physical poses and animations:

- `walk`, `rest`, `stand`, `swim`, `dance`, `wave`, `point`
- `pushup`, `bow`, `cute`, `freaky`, `worm`, `shake`, `shrug`
- `dead`, `crab`, `idle`, `idle_blink`

#### Conversational Faces

Designed for expressive communication and voice assistant integration:

- **Base emotions**: `happy`, `sad`, `angry`, `surprised`, `sleepy`, `love`, `excited`, `confused`, `thinking`
- **Talk variants**: `talk_happy`, `talk_sad`, `talk_angry`, `talk_surprised`, `talk_sleepy`, `talk_love`, `talk_excited`, `talk_confused`, `talk_thinking`

The "talk_" variants feature open mouths for lip-sync and animated speech. These faces are perfect for:

- Voice assistant projects (Alexa, Google Assistant, custom TTS)
- Chatbot interfaces controlled via the JSON API
- Interactive storytelling and educational applications
- Remote-controlled performances

#### Special Faces

- `default` - The startup/fallback face
- `idle` - Gentle breathing animation for idle state
- `idle_blink` - Blink animation triggered randomly during idle

### Adding Custom Faces

### Workflow:

1. **Image Creation**: Find faces using Kaomoji or [Emojicombos](https://emojicombos.com/kaomoji). Create a `128x64` image in a tool like [jsPaint](https://jspaint.app/).
2. **Bitmap Conversion**: Use [image2cpp](https://javl.github.io/image2cpp/) with `Horizontal` scaling, `128x64` resolution, and `Arduino Code` output.
3. **Registration**:
   - Add your face name to the `FACE_LIST` macro in [face-bitmaps.h](face-bitmaps.h).
   - Paste the generated C array into [face-bitmaps.h](face-bitmaps.h) right after the last bitmap in the list.
   - (Optional) For animations, add numbered suffixes (e.g., `_1`, `_2`) and register the FPS in the `faceFpsEntries` in [sesame-firmware-main.ino](sesame-firmware-main.ino).

### Animating Faces

For an animation to be recognized by the `MAKE_FACE_FRAMES` macro, your array names in [face-bitmaps.h](face-bitmaps.h) must follow a strict naming convention:

- **Root Frame**: `epd_bitmap_myface` (This is required and acts as frame 0).
- **Subsequent Frames**: `epd_bitmap_myface_1`, `epd_bitmap_myface_2`, etc.
- **Limit**: The default system supports up to 6 frames per face (Root + 5 numbered frames).
- **Animation Modes**: Animations can be configured to play as a `LOOP` (restarts at frame 0), `ONCE` (stops on the final frame), or `BOOMERANG` (plays forward then reverses). These modes are typically defined in [movement-sequences.h](movement-sequences.h) when triggerring a pose.

### Macro System

The `FACE_LIST` macro uses X-Macros to automatically generate variable declarations and registration objects:

```cpp
#define FACE_LIST \
    X(walk) \
    X(rest) \
    X(my_new_face) // Just add this line!
```

This eliminates the need to manually update multiple switch statements or arrays when adding new assets.

## Execution & Deployment

1. **Toolchain**: Configure your IDE for `ESP32 Dev Module` or `Lolin S2 Mini`.
2. **Calibration**: Use the Serial Monitor (115200) to send manual step commands (e.g., `rn wf`).
3. **Power Management**: If the robot brownouts during movement, increase `motorCurrentDelay` in the web settings to further stagger servo bursts.

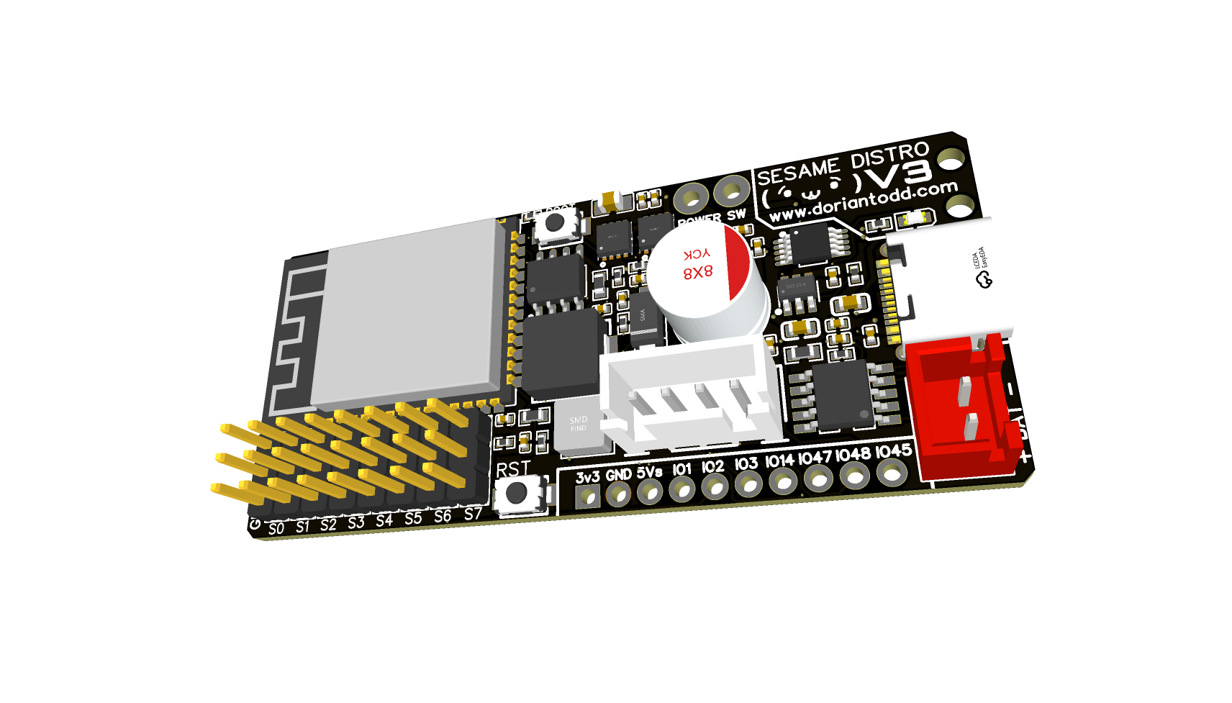
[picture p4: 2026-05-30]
hardware/pcb/distro-v3/assets/design-v3.png

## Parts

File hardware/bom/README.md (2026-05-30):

# Bill of Materials

Every part required to assemble Sesame is cataloged here. Pick the wiring strategy that fits your parts bin, then follow the build flow in [docs/build-guide/README.md](../../docs/build-guide/README.md).

> [!NOTE]
> Amazon links below point to representative search results so you can choose local suppliers or equivalent listings. Pricing and availability change frequently. If you don't mind waiting shipping times you can also order direct from manufacturer for much lower rates.

## Core Electronics (Both Builds)

| Item | Qty | Notes | Source |
| --- | --- | --- | --- |
| MG90S all-metal micro servos (180 Deg) | 8 (buy 10 for spares) | Primary hip/leg actuators; includes servo horns but keep extras | [Amazon](https://www.amazon.com/s?k=mg90s+metal+gear+servo+pack+of+8) |
| 0.96" SSD1306 I2C OLED | 1 | 128x64 display that slides into the top cover slot | [Amazon](https://www.amazon.com/s?k=0.96%22+I2C+OLED+SSD1306) |
| USB-C data/power cable | 1 | Needs to carry 5V/3A for flashing and tethered mode | [Amazon](https://www.amazon.com/s?k=usb+c+cable+60w) |
| Rocker power switch (KCD1, panel mount) | 1 | Snaps into the top cover cutout | [Amazon](https://www.amazon.com/s?k=KCD1+mini+rocker+switch+2+pin) |
| 22AWG silicone wire kit | 1 | Power/ground bus lines | [Amazon](https://www.amazon.com/s?k=22awg+silicone+wire+kit) |
| 30AWG silicone wire kit | 1 | Signal leads and dense harnessing | [Amazon](https://www.amazon.com/s?k=30awg+silicone+wire) |
| Heat-shrink assortment | 1 | Insulate OLED, switch, and battery joints | [Amazon](https://www.amazon.com/s?k=heat+shrink+tubing+kit) |
| Small zip ties | 1 pack | Bundling wires inside the frame | [Amazon](https://www.amazon.com/s?k=mini+zip+ties) |

## Wiring Option A – S2 Mini / Hand-Wired Harness

| Item | Qty | Notes | Source |
| --- | --- | --- | --- |
| Lolin/WeMos ESP32-S2 Mini | 1 | Native USB-C, fits on perfboard for the hand-wired build | [Amazon](https://www.amazon.com/s?k=esp32+s2+mini) |
| Small protoboard (approx. 5×7 cm) | 1 | Hosts the header matrix and rails | [Amazon](https://www.amazon.com/s?k=prototype+perfboard) |
| 3-pin male headers | 8 | Build the servo breakout; match spacing to MG90 plugs | [Amazon](https://www.amazon.com/s?k=pin+header+strip) |
| Buck converter (5–12 V in to stable 5V/3A out) | 1 | Powers motors + MCU when using batteries | [Amazon](https://www.amazon.com/s?k=3a+dc+dc+buck+converter+module) |

## Wiring Option B – Sesame Distro Board V3/V2 (Included in Build Kits)

> [!NOTE]
> If you purchased a Sesame Build Kit, your V2 Distro Board is already assembled, pre-flashed, and included. You don't need to order these parts separately.

| Item | Qty | Notes | Source |
| --- | --- | --- | --- |
| Sesame Distro Board V3/V2 PCB | 1 | Fully SMD design. Order with PCBway assembly service or attempt advanced hand soldering. See [ordering guide](/hardware/pcb/README.md) | [GitHub](/hardware/pcb/README.md) |

## Wiring Option C – Sesame Distro Board V1 / ESP32-DevKitC-32E (Legacy)

> [!CAUTION]
> V1 is now phased out but still supported. Only choose this if you already have a V1 board.

| Item | Qty | Notes | Source |
| --- | --- | --- | --- |
| ESP32-DevKitC-32E (ESP32-WROOM-32) | 1 | Base board the Distro Board V1 stacks on. This one is very tricky because its a very specific board. You can use the 32E with the floating pcb antenna OR you can use the 32U but you have to route an antenna inside. | [Amazon](https://www.amazon.com/s?k=ESP32+DevKitC+32) |
| Sesame Distro Board V1 PCB | 1 | Order `Gerber_Sesame-Distro-Board_PCB_Sesame-Distro-Board_V1.zip` via PCBway | [GitHub](/hardware/pcb/README.md) |
| 5V buck converter (same spec as above) | 1 | Mounts on the distro board pads | [Amazon](https://www.amazon.com/s?k=3a+dc+dc+buck+converter+module) |
| 1000 µF electrolytic capacitor | 1 | Smooths output voltage on buck converter; 10V+ rating recommended | [Amazon](https://www.amazon.com/s?k=1000uf+electrolytic+capacitor) |
| 4-pin JST-XH or PH header | 1 | Optional external connector footprint on PCB | [Amazon](https://www.amazon.com/s?k=jst+xh+4+pin+kit) |
| 2-pin screw terminal (2.54 mm pitch) | 1 | Optional battery input on PCB | [Amazon](https://www.amazon.com/s?k=2+pin+screw+terminal+block+2.54mm+pitch) |
| M2.5 × 5 mm male-female standoffs | 4 | Elevate the PCB over the DevKit mounting holes | [Amazon](https://www.amazon.com/s?k=m2.5+male+female+standoff+5mm) |

## Power Sources & Connectors

| Item | Qty | Notes | Source |
| --- | --- | --- | --- |
| Bambu Lab 14500 7.4V 800mAh Li-ion Battery | 1 | Recommended wireless pack; cheap, effective, designed to fit inside the new internal frame. | [Bambu Lab](https://us.store.bambulab.com/products/14500-7-4v-800mah-li-ion-battery-1pcs) |
| Bambu Lab 7.4V Lithium battery charger | 1 | Matching charger for the 14500 battery with XH2.54 connector. | [Bambu Lab](https://us.store.bambulab.com/products/7-4v-lithium-battery-charger-with-xh2-54-connector-1pcs?id=593290727051776002) |
| XH2.54 female pigtail | 1 | Interface battery to switch/PCB without cutting stock leads (V3 requires soldering). | [Amazon](https://www.amazon.com/s?k=xh2.54+pigtail+cable) |

## Fasteners & Mechanical Hardware

| Item | Qty | Usage | Amazon |
| --- | --- | --- | --- |
| M2 × 5 mm self-threading screws | ~40 | All plastic joints, OLED retention, motor mounts, and covers (Can just get a variety pack) | [Amazon](https://www.amazon.com/s?k=m2+self+tapping+screws+kit) |
| M2.5 × 5mm machine screws | 10 | Servo horn attachment to servo shafts only. Included servo horn screws are usually too short. | [Amazon](https://www.amazon.com/s?k=m2+machine+screw+kit) |

## 3D Printed Parts

Print the 11-part part set outlined in [printing/README.md](../printing/README.md). STL and CAD sources live under `hardware/printing/`.

## Consumables & Tools Checklist

| Item | Notes | Source |
| --- | --- | --- |
| Leaded solder (0.6–0.8 mm) | Easier flow for dense perfboard work | [Amazon](https://www.amazon.com/s?k=63%2F37+solder+0.8mm) |
| Flux pen | Protects pads on the perfboard and PCB | [Amazon](https://www.amazon.com/s?k=flux+pen) |
| Solder wick / pump | For rework on the OLED pins | [Amazon](https://www.amazon.com/s?k=solder+wick) |
| Small flush cutters | Trim servo leads, perfboard traces, or supports | [Amazon](https://www.amazon.com/s?k=flush+cutters) |
| Precision screwdriver set | Needed for self-tapping M2 hardware | [Amazon](https://www.amazon.com/s?k=precision+screwdriver+set) |

## Power & Safety Notes

- Sesame needs at least 5 V at 3 A available at the rails. 
- **Lolin S2 Mini:** Can be powered via USB-C PD (5V/3A capable) for tethered operation, or via battery + buck converter.
- **Distro Board V3/V2:** Supports both USB-C PD (5V/3A) for tethered operation AND battery + buck converter. Included in all Sesame Build Kits.
- **Distro Board V1 (Legacy):** Cannot run on tethered USB-C power due to design limitations. Must use battery + buck converter for operation.
- When battery powering either build, route the pack through the rocker switch and buck converter before it touches the rails, mirroring the schematic in [docs/wiring-guide/README.md](../../docs/wiring-guide/README.md).
- **Never cut the factory battery connector off the pack.** Instead, create adapter pigtails using XT30 or JST RCY leads so the pack remains chargeable.
- A Bambu Lab 14500 7.4V 800mAh Li-ion battery fits the new stock battery cavity (V3 requires printing the new internal frame).
- **Always apply heat shrink tubing to connectors**. Be extremely careful when cutting and soldering battery connectors. If you are still using the legacy 10440 solution make sure the cells are removed during soldering.

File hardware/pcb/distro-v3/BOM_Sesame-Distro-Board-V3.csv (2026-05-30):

ID | Name | Designator | Footprint | Quantity | Manufacturer Part | Manufacturer | Supplier | Supplier Part | Price
1 | 1uF | C10 | C0402 | 1 | CC0402MRY5V6BB105 | YAGEO(国巨) | LCSC | C527031 | 0.006
2 | XY-XH2.54-2A11-R | CN1 | CONN-TH_2P-P2.50_C9900022029 | 1 | XY-XH2.54-2A11-R | XYECONN(辛译) | LCSC | C22391422 | 0.015
3 | 1kΩ | R4,R3 | R0402 | 2 | 0402WGF1001TCE | UNI-ROYAL(厚声) | LCSC | C11702 | 0.001
4 | 10kΩ | R8,R5,R7,R12,R15 | R0402 | 5 | 0402WGF1002TCE | UNI-ROYAL(厚声) | LCSC | C25744 | 0.001
5 | HX 3X4X2-2P-1.6N TACTILE SWITCH | RST,BOOT | KEY-SMD_L4.0-W3.0-LS4.9-1 | 2 | HX 3x4x2-2P-1.6N TACTILE SWITCH | hanxia(韩下) | LCSC | C49234124 | 0.019
6 | HOLE 1.5 | H3,H4 | HOLEHOLE | 2 |  |  |  | No Part Required
7 | LTC4416EMS#PBF | U7 | MSOP-10_L3.0-W3.0-P0.50-LS5.0-BL | 1 | LTC4416EMS#PBF | ADI(亚德诺) | LCSC | C694754 | 8.147
8 | 820uF | C1 | CAP-TH_BD8.0-P3.50-D0.6-FD | 1 | E2821M010D120RL | 瑞隆 | LCSC | C2898774 | 0.123
9 | 100nF | C2,C7,C18 | C0402 | 3 | VJ0402Y104KXJPW1BC | VISHAY(威世) | LCSC | C3891429 | 0.073
10 | 10nF | C4 | C0402 | 1 | CL05B103KB5NNNC | SAMSUNG(三星) | LCSC | C15195 | 0.002
11 | 1uF | C5 | C0402 | 1 | CL05A105KA5NQNC | SAMSUNG(三星) | LCSC | C52923 | 0.005
12 | 100nF | C11,C_MUX1,C_MUX2,C_MUX3 | C0402 | 4 | MC0402B104K500N5RH | Sunway(信维通信) | LCSC | C3152552
13 | 10uF | C12,C13,C14NB | C0402 | 3 | CL05A106MQ5NUNC | SAMSUNG(三星) | LCSC | C15525 | 0.017
14 | 47pF | C19 | C0402 | 1 | 0402CG470J500NT | FH(风华) | LCSC | C1567 | 0.001
15 | 4.7kΩ | R1,R13 | R0402 | 2 | 0402WGF4701TCE | UNI-ROYAL(厚声) | LCSC | C25900 | 0.001
16 | 100kΩ | R9 | R0402 | 1 | 0402WGF1003TCE | UNI-ROYAL(厚声) | LCSC | C25741 | 0.001
17 | 24kΩ | R11 | R0603 | 1 | 0603WAF2402T5E | UNI-ROYAL(厚声) | LCSC | C23352 | 0.002
18 | 33kΩ | R14 | R0402 | 1 | 0402WGF3302TCE | UNI-ROYAL(厚声) | LCSC | C25779 | 0.001
19 | 10nF | C3 | C0805 | 1 | CL21B103KBANNNC | SAMSUNG(三星) | LCSC | C1710 | 0.008
20 | 3.3nF | C6 | C0603 | 1 | CL10B332KB8NNNC | SAMSUNG(三星) | LCSC | C1613 | 0.006
21 | 22uF | C8,C9,C17 | C0603 | 3 | CL10A226MQ8NRNC | SAMSUNG(三星) | LCSC | C59461 | 0.013
22 | SS54_C123946 | D1 | SMA_L4.4-W2.8-LS5.4-RD | 1 | SS54 | 晶导微电子 | LCSC | C123946 | 0.052
23 | JST-XH-4-PIN | JST1 | JST-XH-4PIN-2.5 | 1 |  |  |  | C144395 | 0.054
24 | 4.7uH | L1 | IND-SMD_L7.0-W6.6_APH0630 | 1 | APH0630T4R7M | APV(爱普微) | LCSC | C5349705 | 0.072
25 | KT-0603R | LED1 | LED0603-RD | 1 | KT-0603R | KENTO | LCSC | C2286 | 0.007
26 | CSD25402Q3A | Q_BAT,Q_USB | VSONP-8_L3.1-W3.1-P0.65-LS3.5-BL | 2 | CSD25402Q3A | TI(德州仪器) | LCSC | C111356 | 0.638
27 | 62kΩ | R2 | R0603 | 1 | RT0603BRD0762KL | YAGEO(国巨) | LCSC | C136961 | 0.026
28 | 45.3kΩ | R6 | R0603 | 1 | RMC 0603 45K3 F N | Tyohm(幸亚电阻) | LCSC | C325695 | 0.004
29 | HX | S0 | HDR-TH_3P-P2.54-V-M-1 | 1 | HX PH254-01-03-Z-L11.5 pcb pin header | hanxia(韩下) | LCSC | C52016391 | 0.023
30 | HX PH254-01-03-Z-L11.5 PCB PIN HEADER | S1,S2,S3,S4,S5,S6,S7 | HDR-TH_3P-P2.54-V-M-1 | 7 | HX PH254-01-03-Z-L11.5 pcb pin header | hanxia(韩下) | LCSC | C52016391 | 0.023
31 | ESP32-S3-WROOM-1(N16R8) | U1 | WIRELM-SMD_ESP32-S3-WROOM-1 | 1 | ESP32-S3-WROOM-1-N16R8 | ESPRESSIF(乐鑫) | LCSC | C2913202 | 5.389
32 | TPS54531DDA | U2 | SOIC-8_L4.9-W3.9-P1.27-LS6.0-BL-EP2.9 | 1 | TPS54531DDA | TI(德州仪器) | LCSC | C544938 | 0.631
33 | SY8120B1ABC | U3 | SOT-23-6_L2.9-W1.6-P0.95-LS2.8-BL | 1 | SY8120B1ABC | Silergy(矽力杰) | LCSC | C88474 | 0.161
34 | 4.7uH | U4 | IND-SMD_L4.4-W4.2 | 1 | APH0420T4R7M | APV(爱普微) | LCSC | C5349668 | 0.081
35 | EXPANSION HEADER | U6 | HEADER MALE 2.54-1*10 | 1 |  |  |  | No Part Required
36 | CH224K | U8 | ESSOP-10_L4.9-W3.9-P1.0-LS6.0-TL-EP | 1 | CH224K | WCH(南京沁恒) | LCSC | C970725 | 0.616
37 | TYPE-C-31-M-12 | USBC1 | USB-C_SMD-TYPE-C-31-M-12_1 | 1 | TYPE-C-31-M-12 | 韩国韩荣 | LCSC | C165948 | 0.188

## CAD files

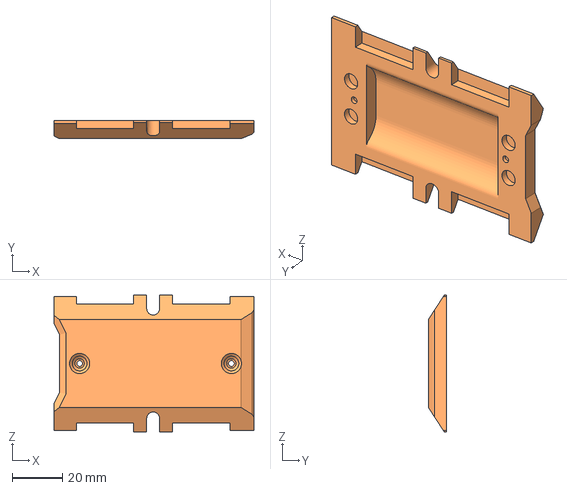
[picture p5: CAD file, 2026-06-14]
hardware/cad/Bottom-Cover.3mf
79.2 x 7.27 x 54.2 mm

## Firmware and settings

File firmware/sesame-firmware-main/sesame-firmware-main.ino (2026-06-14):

#include <WiFi.h>
#include <WebServer.h>
#include <DNSServer.h>
#include <ESPmDNS.h>
#include <Wire.h>
#include <Adafruit_PWMServoDriver.h>
#include <Adafruit_GFX.h>
#include <Adafruit_SSD1306.h>
#include "face-bitmaps.h"
#include "movement-sequences.h"
#include "captive-portal.h"

// --- Access Point Configuration ---
// This is the network the Robot will create
#define AP_SSID  "Sesame-Controller"
#define AP_PASS  "12345678" // Must be at least 8 characters

// --- Station Mode Configuration (Optional) ---
// Set these to connect to your home/office WiFi network
// Leave NETWORK_SSID empty to disable station mode
#define NETWORK_SSID ""  // Your WiFi network name
#define NETWORK_PASS ""  // Your WiFi password
#define ENABLE_NETWORK_MODE false  // Set to true to enable network connection attempts

#define SCREEN_WIDTH 128
#define SCREEN_HEIGHT 64
#define OLED_RESET -1
#define OLED_I2C_ADDR 0x3C
#define OLED_I2C_ADDR_ALT 0x3D
#define PCA9685_I2C_ADDR 0x40

#define SERVO_MIN_US 500
#define SERVO_MAX_US 2500
#define SERVO_FREQUENCY_HZ 50

// DNS Server for Captive Portal
DNSServer dnsServer;
const byte DNS_PORT = 53;

Adafruit_SSD1306 display(SCREEN_WIDTH, SCREEN_HEIGHT, &Wire, OLED_RESET);
Adafruit_PWMServoDriver pwm(PCA9685_I2C_ADDR);
WebServer server(80);

// Global state for animations
String currentCommand = "";
String currentFaceName = "default";
const unsigned char* const* currentFaceFrames = nullptr;
uint8_t currentFaceFrameCount = 0;
uint8_t currentFaceFrameIndex = 0;
unsigned long lastFaceFrameMs = 0;
int faceFps = 8;
FaceAnimMode currentFaceMode = FACE_ANIM_LOOP;
int8_t faceFrameDirection = 1;
bool faceAnimFinished = false;
int currentFaceFps = 0;
bool idleActive = false;
bool idleBlinkActive = false;
unsigned long nextIdleBlinkMs = 0;
uint8_t idleBlinkRepeatsLeft = 0;

// WiFi Info Scrolling
unsigned long lastInputTime = 0;
bool firstInputReceived = false;
bool showingWifiInfo = false;
int wifiScrollPos = 0;
unsigned long lastWifiScrollMs = 0;
String wifiInfoText = "";

// Network Mode
bool networkConnected = false;
IPAddress networkIP;
String deviceHostname = "sesame-robot";

// PCA9685 Servo Driver
// ======================================================================
// Connect the eight servos to PCA9685 channels 0-7 in the same order used
// by movement-sequences.h. The PCA9685 and OLED share the I2C bus.
// ======================================================================

// Subtrim values for each servo (offset in degrees)
int8_t servoSubtrim[8] = {0, 0, 0, 0, 0, 0, 0, 0};


// Animation constants
int frameDelay = 100;
int walkCycles = 10;
int motorCurrentDelay = 20; // ms delay between motor movements to prevent over-current

struct FaceEntry {
  const char* name;
  const unsigned char* const* frames;
  uint8_t maxFrames;
};

static const uint8_t MAX_FACE_FRAMES = 6;

#define MAKE_FACE_FRAMES(name) \
  const unsigned char* const face_##name##_frames[] = { \
    epd_bitmap_##name, epd_bitmap_##name##_1, epd_bitmap_##name##_2, \
    epd_bitmap_##name##_3, epd_bitmap_##name##_4, epd_bitmap_##name##_5 \
  };

#define X(name) MAKE_FACE_FRAMES(name)
FACE_LIST
#undef X
#undef MAKE_FACE_FRAMES

const FaceEntry faceEntries[] = {
#define X(name) { #name, face_##name##_frames, MAX_FACE_FRAMES },
  FACE_LIST
#undef X
  { "default", face_defualt_frames, MAX_FACE_FRAMES }
};

struct FaceFpsEntry {
  const char* name;
  uint8_t fps;
};

const FaceFpsEntry faceFpsEntries[] = {
  { "walk", 1 },
  { "rest", 1 },
  { "swim", 1 },
  { "dance", 1 },
  { "wave", 1 },
  { "point", 5 },
  { "stand", 1 },
  { "cute", 1 },
  { "pushup", 1 },
  { "freaky", 1 },
  { "bow", 1 },
  { "worm", 1 },
  { "shake", 1 },
  { "shrug", 1 },
  { "dead", 2 },
  { "crab", 1 },
  { "idle", 1 },
  { "idle_blink", 7 },
  { "default", 1 },
  // Conversational faces (manually controlled by Python - no auto-animation)
  { "happy", 1 },
  { "talk_happy", 1 },
  { "sad", 1 },
  { "talk_sad", 1 },
  { "angry", 1 },
  { "talk_angry", 1 },
  { "surprised", 1 },
  { "talk_surprised", 1 },
  { "sleepy", 1 },
  { "talk_sleepy", 1 },
  { "love", 1 },
  { "talk_love", 1 },
  { "excited", 1 },
  { "talk_excited", 1 },
  { "confused", 1 },
  { "talk_confused", 1 },
  { "thinking", 1 },
  { "talk_thinking", 1 },
};


// Prototypes
void setServoAngle(uint8_t channel, int angle);
bool i2cDevicePresent(uint8_t address);
uint8_t detectOledAddress();
void updateFaceBitmap(const unsigned char* bitmap);
void setFace(const String& faceName);
void setFaceMode(FaceAnimMode mode);
void setFaceWithMode(const String& faceName, FaceAnimMode mode);
void updateAnimatedFace();
void delayWithFace(unsigned long ms);
void enterIdle();
void exitIdle();
void updateIdleBlink();
int getFaceFpsForName(const String& faceName);
bool pressingCheck(String cmd, int ms);
void handleGetSettings();
void handleSetSettings();
void handleGetStatus();
void handleApiCommand();
void updateWifiInfoScroll();
void recordInput();

void handleRoot() {
  server.send(200, "text/html", index_html);
}

void handleCommandWeb() {
  // We send 200 OK immediately so the web browser doesn't hang waiting for animation to finish
  if (server.hasArg("pose")) {
    currentCommand = server.arg("pose");
    recordInput();
    exitIdle();
    server.send(200, "text/plain", "OK"); 
  } 
  else if (server.hasArg("go")) {
    currentCommand = server.arg("go");
    recordInput();
    exitIdle();
    server.send(200, "text/plain", "OK");
  } 
  else if (server.hasArg("stop")) {
    currentCommand = "";
    recordInput();
    server.send(200, "text/plain", "OK");
  }
  else if (server.hasArg("motor") && server.hasArg("value")) {
    int motorNum = server.arg("motor").toInt();
    int servoIdx = servoNameToIndex(server.arg("motor"));
    int angle = server.arg("value").toInt();
    if (motorNum >= 1 && motorNum <= 8 && angle >= 0 && angle <= 180) {
      setServoAngle(motorNum - 1, angle); // Convert 1-based to 0-based index
      recordInput();
      server.send(200, "text/plain", "OK");
    } else if (servoIdx != -1 && angle >= 0 && angle <= 180) {
      setServoAngle(servoIdx, angle);
      recordInput();
      server.send(200, "text/plain", "OK");
    } else {
      server.send(400, "text/plain", "Invalid motor or angle");
    }
  }
  else {
    server.send(400, "text/plain", "Bad Args");
  }
}

void handleGetSettings() {
  String json = "{";
  json += "\"frameDelay\":" + String(frameDelay) + ",";
  json += "\"walkCycles\":" + String(walkCycles) + ",";
  json += "\"motorCurrentDelay\":" + String(motorCurrentDelay) + ",";
  json += "\"faceFps\":" + String(faceFps);
  json += "}";
  server.send(200, "application/json", json);
}

void handleSetSettings() {
  if (server.hasArg("frameDelay")) frameDelay = server.arg("frameDelay").toInt();
  if (server.hasArg("walkCycles")) walkCycles = server.arg("walkCycles").toInt();
  if (server.hasArg("motorCurrentDelay")) motorCurrentDelay = server.arg("motorCurrentDelay").toInt();
  if (server.hasArg("faceFps")) faceFps = (int)max(1L, server.arg("faceFps").toInt());
  server.send(200, "text/plain", "OK");
}

// API endpoint for network clients to get robot status
void handleGetStatus() {
  String json = "{";
  json += "\"currentCommand\":\"" + currentCommand + "\",";
  json += "\"currentFace\":\"" + currentFaceName + "\",";
  json += "\"networkConnected\":" + String(networkConnected ? "true" : "false") + ",";
  json += "\"apIP\":\"" + WiFi.softAPIP().toString() + "\"";
  if (networkConnected) {
    json += ",\"networkIP\":\"" + networkIP.toString() + "\"";
  }
  json += "}";
  server.send(200, "application/json", json);
}

// API endpoint for network clients to send commands (JSON-based)
void handleApiCommand() {
  if (server.method() != HTTP_POST) {
    server.send(405, "application/json", "{\"error\":\"Method not allowed\"}");
    return;
  }
  
  String body = server.arg("plain");
  
  Serial.println("API Command received:");
  Serial.println(body);
  
  // Check for face-only command (no movement)
  int faceOnlyStart = body.indexOf("\"face\":\"");
  if (faceOnlyStart == -1) {
    faceOnlyStart = body.indexOf("\"face\": \"");
  }
  
  // If we have a face but no command field, it's face-only
  bool faceOnly = (faceOnlyStart > 0 && body.indexOf("\"command\":") == -1 && body.indexOf("\"command\": ") == -1);
  
  String command = "";
  String face = "";
  
  // Parse face
  if (faceOnlyStart > 0) {
    faceOnlyStart = body.indexOf("\"", faceOnlyStart + 6) + 1;
    int faceEnd = body.indexOf("\"", faceOnlyStart);
    if (faceEnd > faceOnlyStart) {
      face = body.substring(faceOnlyStart, faceEnd);
      Serial.print("Parsed face: ");
      Serial.println(face);
    }
  }
  
  // Parse command (if not face-only)
  if (!faceOnly) {
    int cmdStart = body.indexOf("\"command\":\"");
    if (cmdStart == -1) {
      cmdStart = body.indexOf("\"command\": \"");
    }
    
    if (cmdStart == -1) {
      Serial.println("Error: command field not found");
      server.send(400, "application/json", "{\"error\":\"Missing command field\"}");
      return;
    }
    
    cmdStart = body.indexOf("\"", cmdStart + 10) + 1;
    int cmdEnd = body.indexOf("\"", cmdStart);
    
    if (cmdEnd <= cmdStart) {
      Serial.println("Error: invalid command format");
      server.send(400, "application/json", "{\"error\":\"Invalid command format\"}");
      return;
    }
    
    command = body.substring(cmdStart, cmdEnd);
    Serial.print("Parsed command: ");
    Serial.println(command);
  }
  
  // Set face if provided
  if (face.length() > 0) {
    setFace(face);
  }
  
  // If face-only, just acknowledge
  if (faceOnly) {
    recordInput();
    server.send(200, "application/json", "{\"status\":\"ok\",\"message\":\"Face updated\"}");
    return;
  }
  
  // Execute command
  if (command == "stop") {
    currentCommand = "";
    recordInput();
    server.send(200, "application/json", "{\"status\":\"ok\",\"message\":\"Command stopped\"}");
  } else {
    currentCommand = command;
    recordInput();
    exitIdle();
    server.send(200, "application/json", "{\"status\":\"ok\",\"message\":\"Command executed\"}");
  }
}

void setup() {
  Serial.begin(115200);
  randomSeed(micros());
  
  // Use the board's default I2C pins, matching the working spider sketch.
  // A classic ESP32 uses SDA 21 and SCL 22 by default.
  Wire.begin();

  // OLED Init
  uint8_t oledAddress = detectOledAddress();
  if (oledAddress == 0 || !display.begin(SSD1306_SWITCHCAPVCC, oledAddress)) {
    Serial.println(F("SSD1306 allocation failed."));
    while (1);
  }
  Serial.print(F("SSD1306 initialized at 0x"));
  Serial.println(oledAddress, HEX);
  
  display.clearDisplay();
  display.setTextColor(SSD1306_WHITE);
  display.setTextSize(1);
  display.setCursor(0,0);
  display.println(F("Setting up WiFi..."));
  display.display();

  // --- WIFI CONFIGURATION ---
  // Try to connect to network first if configured
  if (ENABLE_NETWORK_MODE && String(NETWORK_SSID).length() > 0) {
    Serial.println("Attempting to connect to network: " + String(NETWORK_SSID));
    WiFi.mode(WIFI_AP_STA); // Enable both AP and Station modes
    WiFi.setHostname(deviceHostname.c_str());
    WiFi.begin(NETWORK_SSID, NETWORK_PASS);
    
    // Wait up to 10 seconds for connection
    int attempts = 0;
    while (WiFi.status() != WL_CONNECTED && attempts < 20) {
      delay(500);
      Serial.print(".");
      attempts++;
    }
    
    if (WiFi.status() == WL_CONNECTED) {
      networkConnected = true;
      networkIP = WiFi.localIP();
      Serial.println();
      Serial.print("Connected to network! IP: ");
      Serial.println(networkIP);
    } else {
      Serial.println();
      Serial.println("Failed to connect to network. Running in AP-only mode.");
      WiFi.mode(WIFI_AP); // Fall back to AP-only
    }
  } else {
    WiFi.mode(WIFI_AP);
    Serial.println("Network mode disabled. Running in AP-only mode.");
  }
  
  // --- ACCESS POINT CONFIGURATION ---
  WiFi.softAP(AP_SSID, AP_PASS);
  IPAddress myIP = WiFi.softAPIP();
  
  Serial.print("AP Created. IP: ");
  Serial.println(myIP);

  // Build WiFi info text for scrolling
  if (networkConnected) {
    wifiInfoText = "AP: " + String(AP_SSID) + " (" + myIP.toString() + ")  |  Network: " + String(NETWORK_SSID) + " (" + networkIP.toString() + ") or " + deviceHostname + ".local  |  ";
  } else {
    wifiInfoText = "Connect to WiFi: " + String(AP_SSID) + "  |  Pass: " + String(AP_PASS) + "  |  IP: " + myIP.toString() + "  |  Captive Portal will auto-open!  |  ";
  }
  
  // Initialize input tracking
  lastInputTime = millis();
  firstInputReceived = false;
  showingWifiInfo = false;

  // Start mDNS responder for local network discovery
  if (MDNS.begin(deviceHostname.c_str())) {
    Serial.println("mDNS responder started");
    Serial.print("Access controller at: http://");
    Serial.print(deviceHostname);
    Serial.println(".local");
    MDNS.addService("http", "tcp", 80);
  } else {
    Serial.println("Error setting up mDNS responder!");
  }

  // Start DNS Server for Captive Portal
  // This redirects ALL domain requests to the ESP32's IP
  dnsServer.start(DNS_PORT, "*", myIP);

  // Web Server Routes
  server.on("/", handleRoot);
  server.on("/cmd", handleCommandWeb);
  server.on("/getSettings", handleGetSettings);
  server.on("/setSettings", handleSetSettings);
  
  // API endpoints for network communication
  server.on("/api/status", handleGetStatus);
  server.on("/api/command", handleApiCommand);
  
  // Catch-all route for captive portal
  // This ensures any URL redirects to the controller page
  server.onNotFound(handleRoot);
  
  server.begin();

  // PCA9685 servo driver init. It shares SDA/SCL with the OLED at 0x3C/0x3D.
  if (!pwm.begin()) {
    Serial.println(F("PCA9685 not found at 0x40."));
    while (1);
  }
  pwm.setPWMFreq(SERVO_FREQUENCY_HZ);
  Serial.println(F("PCA9685 initialized at 0x40, servo frequency 50 Hz"));
  delay(10);
  
  // Show rest face on startup without moving motors
  setFace("rest");
  
  Serial.println(F("HTTP server & Captive Portal started."));
}

void loop() {
  // Process DNS requests for captive portal
  dnsServer.processNextRequest();
  
  server.handleClient();
  updateAnimatedFace();
  updateIdleBlink();
  updateWifiInfoScroll();

  if (currentCommand != "") {
    String cmd = currentCommand;
    if (cmd == "forward") runWalkPose();
    else if (cmd == "backward") runWalkBackward();
    else if (cmd == "left") runTurnLeft();
    else if (cmd == "right") runTurnRight();
    else if (cmd == "rest") { runRestPose(); if (currentCommand == "rest") currentCommand = ""; }
    else if (cmd == "stand") { runStandPose(1); if (currentCommand == "stand") currentCommand = ""; }
    else if (cmd == "wave") runWavePose();
    else if (cmd == "dance") runDancePose();
    else if (cmd == "swim") runSwimPose();
    else if (cmd == "point") runPointPose();
    else if (cmd == "pushup") runPushupPose();
    else if (cmd == "bow") runBowPose();
    else if (cmd == "cute") runCutePose();
    else if (cmd == "freaky") runFreakyPose();
    else if (cmd == "worm") runWormPose();
    else if (cmd == "shake") runShakePose();
    else if (cmd == "shrug") runShrugPose();
    else if (cmd == "dead") runDeadPose();
    else if (cmd == "crab") runCrabPose();
  }
  
  // Serial CLI for debugging (can be used to diagnose servo position issues and wiring)
  if (Serial.available()) {
    static char command_buffer[32];
    static byte buffer_pos = 0;
    char c = Serial.read();
    if (c == '\n' || c == '\r') {
      if (buffer_pos > 0) {
        command_buffer[buffer_pos] = '\0';
        int motorNum, angle;
        recordInput();
        if(strcmp(command_buffer, "run walk") == 0 || strcmp(command_buffer, "rn wf") == 0) { currentCommand = "forward"; runWalkPose(); currentCommand = ""; }
        else if(strcmp(command_buffer, "rn wb") == 0) { currentCommand = "backward"; runWalkBackward(); currentCommand = ""; }
        else if(strcmp(command_buffer, "rn tl") == 0) { currentCommand = "left"; runTurnLeft(); currentCommand = ""; }
        else if(strcmp(command_buffer, "rn tr") == 0) { currentCommand = "right"; runTurnRight(); currentCommand = ""; }
        else if(strcmp(command_buffer, "run rest") == 0 || strcmp(command_buffer, "rn rs") == 0) runRestPose();
        else if(strcmp(command_buffer, "run stand") == 0 || strcmp(command_buffer, "rn st") == 0) runStandPose(1);
        else if(strcmp(command_buffer, "rn wv") == 0) { currentCommand = "wave"; runWavePose(); }
        else if(strcmp(command_buffer, "rn dn") == 0) { currentCommand = "dance"; runDancePose(); }
        else if(strcmp(command_buffer, "rn sw") == 0) { currentCommand = "swim"; runSwimPose(); }
        else if(strcmp(command_buffer, "rn pt") == 0) { currentCommand = "point"; runPointPose(); }
        else if(strcmp(command_buffer, "rn pu") == 0) { currentCommand = "pushup"; runPushupPose(); }
        else if(strcmp(command_buffer, "rn bw") == 0) { currentCommand = "bow"; runBowPose(); }
        else if(strcmp(command_buffer, "rn ct") == 0) { currentCommand = "cute"; runCutePose(); }
        else if(strcmp(command_buffer, "rn fk") == 0) { currentCommand = "freaky"; runFreakyPose(); }
        else if(strcmp(command_buffer, "rn wm") == 0) { currentCommand = "worm"; runWormPose(); }
        else if(strcmp(command_buffer, "rn sk") == 0) { currentCommand = "shake"; runShakePose(); }
        else if(strcmp(command_buffer, "rn sg") == 0) { currentCommand = "shrug"; runShrugPose(); }
        else if(strcmp(command_buffer, "rn dd") == 0) { currentCommand = "dead"; runDeadPose(); }
        else if(strcmp(command_buffer, "rn cb") == 0) { currentCommand = "crab"; runCrabPose(); }
        else if (strcmp(command_buffer, "subtrim") == 0 || strcmp(command_buffer, "st") == 0) {
          Serial.println("Subtrim values:");
          for (int i = 0; i < 8; i++) {
            Serial.print("Motor "); Serial.print(i); Serial.print(": ");
            if (servoSubtrim[i] >= 0) Serial.print("+");
            Serial.println(servoSubtrim[i]);
          }
        }
        else if (strcmp(command_buffer, "subtrim save") == 0 || strcmp(command_buffer, "st save") == 0) {
          Serial.println("Copy and paste this into your code:");
          Serial.print("int8_t servoSubtrim[8] = {");
          for (int i = 0; i < 8; i++) {
            Serial.print(servoSubtrim[i]);
            if (i < 7) Serial.print(", ");
          }
          Serial.println("};");
        }
        else if (strncmp(command_buffer, "subtrim reset", 13) == 0 || strncmp(command_buffer, "st reset", 8) == 0) {
          for (int i = 0; i < 8; i++) servoSubtrim[i] = 0;
          Serial.println("All subtrim values reset to 0");
        }
        else if (strncmp(command_buffer, "subtrim ", 8) == 0 || strncmp(command_buffer, "st ", 3) == 0) {
          const char* params = (command_buffer[1] == 't') ? command_buffer + 3 : command_buffer + 8;
          int trimMotor, trimValue;
          if (sscanf(params, "%d %d", &trimMotor, &trimValue) == 2) {
            if (trimMotor >= 0 && trimMotor < 8) {
              if (trimValue >= -90 && trimValue <= 90) {
                servoSubtrim[trimMotor] = trimValue;
                Serial.print("Motor "); Serial.print(trimMotor); Serial.print(" subtrim set to ");
                if (trimValue >= 0) Serial.print("+");
                Serial.println(trimValue);
              } else {
                Serial.println("Subtrim value must be between -90 and +90");
              }
            } else {
              Serial.println("Invalid motor number (0-7)");
            }
          }
        }
        else if (strncmp(command_buffer, "all ", 4) == 0) {
             if (sscanf(command_buffer + 4, "%d", &angle) == 1) {
                 for (int i = 0; i < 8; i++) setServoAngle(i, angle);
                 Serial.print("All servos set to "); Serial.println(angle);
             }
        }
        else if (sscanf(command_buffer, "%d %d", &motorNum, &angle) == 2) {
             if (motorNum >= 0 && motorNum < 8) {
                 setServoAngle(motorNum, angle);
                 Serial.print("Servo "); Serial.print(motorNum); Serial.print(" set to "); Serial.println(angle);
             } else {
                 Serial.println("Invalid motor number (0-7)");
             }
        }
        buffer_pos = 0;
      }
    } else if (buffer_pos < sizeof(command_buffer) - 1) {
      command_buffer[buffer_pos++] = c;
    }
  }
}

// Function to update the robot's face
void updateFaceBitmap(const unsigned char* bitmap) {
  display.clearDisplay();
  display.drawBitmap(0, 0, bitmap, 128, 64, SSD1306_WHITE);
  display.display();
}

uint8_t countFrames(const unsigned char* const* frames, uint8_t maxFrames) {
  if (frames == nullptr || frames[0] == nullptr) return 0;
  uint8_t count = 0;
  for (uint8_t i = 0; i < maxFrames; i++) {
    if (frames[i] == nullptr) break;
    count++;
  }
  return count;
}
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

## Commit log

2026-05-30 Add Distro Board V3 files and update docs
    Add full Sesame Distro Board V3 PCB design and assets and update documentation to reflect V3 as the current board. New files: distro-v3 BOM, Gerbers, PCB JSON, Pick-and-Place, schematic PNG and board images. Updated top-level README, hardware/README, and hardware/bom/README to document V3 features (ESP32-S3 mention, USB-C PD 12V notes, Bambu Lab 14500 battery option), clarify V2/V1 legacy status, and provide ordering/assembly instructions for V3. Small editorial cleanup and power/safety clarifications included.
    This update adresses and solves issues:
    #63 #56 #62
    [BOM_Sesame-Distro-Board-V3.csv, PickAndPlace_PCB_Sesame-Distro-Board-V3.csv]
2026-06-14 Update firmware to use with servo driver
    [Bottom-Cover.3mf]

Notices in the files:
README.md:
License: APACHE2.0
